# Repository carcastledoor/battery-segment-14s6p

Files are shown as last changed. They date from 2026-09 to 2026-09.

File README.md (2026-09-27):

# Formula EV 배터리 · 포트폴리오 근거 자료

제출 포트폴리오 **「AI와 함께 설계한 Formula EV 배터리」**에서 소개한 계산기와 후속 3D 설계 파일입니다. 발표자료의 해당 페이지를 보면서 계산 과정과 실제 설계 산출물을 확인할 수 있습니다.

## 포트폴리오에서 확인할 자료로

| 포트폴리오 | 이 저장소의 자료 | 확인할 내용 |
|---|---|---|
| **7장 · AI 설계 도구** | **[Excel 계산기 다운로드](site/documents/battery-pack-calculator.xlsx)** | 셀 DB 조회, S/P 입력, 전압·용량·에너지·질량·배치 치수 수식 |
| **8장 · 설계안 비교** | **[후보 비교 재현 방법](docs/CALCULATOR.md)** | 24S에서 8P·10P·12P·14P를 대입해 발표자료의 비교값 확인 |
| **17장 · 자연어 기반 3D 설계 확장** | **[모델 확인 안내](docs/VIEWER.md)** · [설계 파일 설명](docs/DESIGN.md) | P45B 세그먼트, 배터리박스, 전장품 배치와 조립·분해 구조 |

**계산기를 먼저 확인하려면:** Excel의 `Battery_Calculator`에서 저장된 Samsung 50S·24S12P 입력과 결과를 확인하세요. 288셀·86.4V·60Ah·5.184kWh가 발표자료의 예시입니다. 8장의 비교는 병렬 수를 바꿔 재현합니다.

**3D 설계를 확인하려면:** 최신 뷰어의 Segment와 Battery Box를 확인하세요. 현재 공개된 실행 주소는 등록되지 않았습니다. [모델 확인 안내](docs/VIEWER.md)에 다운로드와 로컬 실행 방법을 정리했습니다.

## 자료의 범위

계산기는 **2025 실물 프로젝트의 50S·24S12P 설계 탐색**을, 3D 파일은 **17장의 후속 P45B·70S6P 설계 확장**을 뒷받침합니다. 두 설계는 서로 다른 프로젝트 단계입니다.

실물 제작·고장 진단·검차 결과는 포트폴리오 13–16장의 사진과 기록을 참고하세요. 이 저장소의 계산기·후속 모델은 해당 실물 결과를 대신하는 시험 증빙이 아닙니다. [검증 범위](docs/VALIDATION.md)

<details>
<summary>파일 위치</summary>

- `site/documents/`: 계산기 원본
- `site/`: 최신 통합 뷰어
- `docs/`: 계산 재현·모델 설명·확인 범위
- `downloads/`: 배포용 ZIP

비공개 저장소이므로 링크로 검토하려면 접근 권한이 필요합니다. 이전 파일은 Git 이력에 보존되어 있습니다.

</details>

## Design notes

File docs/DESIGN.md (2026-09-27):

# 포트폴리오 17장 · 후속 3D 설계

[처음으로](../README.md)

이 자료는 발표자료 17장의 **자연어 요구 → 3D 형상 → 반복 수정**으로 확장한 설계 산출물입니다. 2025년 제작한 50S 팩의 CAD가 아니라, 당시의 조립·정비 경험을 반영한 다음 시즌 P45B 설계 초안입니다.

## 모델에서 확인할 항목

| 화면 | 확인할 설계 내용 |
|---|---|
| Segment | 셀·홀더·구리/니켈 연결판, A/B 단자 배치, 센싱 PCB와 팬 구조 |
| Battery Box | 5개 세그먼트, 상부 전장품 공간, 버스바 경로, 조립·분해 순서 |
| Description | 셀 선정 기준과 계산기를 패키징에 연결한 설명 |

발표자료의 BMS–버스바 간섭 수정 사례와 연결해 전장품 배치를 볼 수 있습니다. 현재 파일에 모든 수정 단계가 보존된 것은 아니며, 슬라이드의 약 5mm 여유를 독립적으로 재측정한 검사 성적서는 포함하지 않습니다.

## 현재 설계의 계산 기준

사용 셀은 Molicel P45B입니다. 셀 데이터와 직·병렬 수를 직접 만든 계산기에 적용해 전압, 용량, 에너지, 셀 개수와 셀 질량을 검토했습니다.

| 항목 | 현재 설계 기준 |
|---|---:|
| 전체 구성 | 70S6P, 420셀 |
| 세그먼트 | 14S6P × 5개 |
| 공칭 / 최대 전압 | 252V / 294V |
| 용량 / 공칭 에너지 | 27Ah / 6.804kWh |
| 셀 질량 합계 | 28.98kg (69g/셀 기준, 케이스·전장품 제외) |

[계산기 원본](../site/documents/battery-pack-calculator.xlsx)의 저장된 입력은 Samsung 50S·24S12P 예시입니다. 위 수치는 P45B·70S6P를 같은 계산 관계에 적용한 값이며 저장된 입력값과 구분해야 합니다. 셀 정격 전류의 병렬 합을 팩의 검증된 허용 전류로 취급하지 않습니다.

## 패키징으로 연결

- 14S6P 세그먼트의 A/B 단자 배치를 이용해 B–A–B–A–B로 배치합니다.
- 셀 연결부는 니켈 용접 패치와 구리 연결판으로 구성하고, V2 끝단은 ㄱ자 일체형 연결 구조입니다.
- 세그먼트 팬 방향을 통일하고, 하부 세그먼트 공간과 상부 전장품 공간을 구분합니다.
- 양극 전력 경로는 세그먼트 → 퓨즈 → AIR+ → 외부 고전압 커넥터입니다. 음극은 AIR−를 거칩니다.
- 센싱 PCB, BMS, 온도 확장모듈, IMD의 배치와 커넥터 접근 공간을 함께 검토합니다.
- 뚜껑의 안·바깥 측벽이 박스 벽을 감싸며, 팝너트는 뚜껑 안쪽 벽에 배치합니다.
- 조립·분해 화면은 정비 동선을 검토하기 위한 표현입니다. 용접·영구 고정부는 독립적으로 분해하지 않습니다.

배터리박스의 차량 체결 방식은 아직 결정하지 않았습니다. 차량 프레임 화면은 참고 형상이며 장착 설계 확정을 뜻하지 않습니다.

셀 상세, 배열 계산식 및 설계 근거는 웹 뷰어의 Description에서도 확인할 수 있습니다.

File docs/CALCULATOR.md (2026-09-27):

# 포트폴리오 7–8장 · 계산 근거

[처음으로](../README.md) · [계산기 다운로드](../site/documents/battery-pack-calculator.xlsx)

원본 파일은 수정하지 않았습니다. `Battery_Calculator`와 `Cell_DB` 두 시트로 구성됩니다. 셀 모델, S/P, 가로·세로 셀 수, 간격, 방향, 여유를 입력하고 셀 DB를 조회해 결과를 계산합니다.

## 7장 예시 재현

`Battery_Calculator!B4:B6`의 저장값은 Samsung INR21700-50S, 24, 12입니다. `Cell_DB!C4:J4`에 공칭 3.6V, 최대 4.2V, 최소 2.5V, 5Ah, 25A, 72g, 지름 21.45mm, 높이 70.55mm가 있습니다.

| 출력 셀 | 계산 | 결과 |
|---|---|---|
| B16 | 24 × 12 | 288셀 |
| D16 / F16 | 24 × 3.6 / 24 × 4.2 | 공칭 86.4V / 최대 100.8V |
| H16 | 12 × 5Ah | 60Ah |
| B18 | 86.4 × 60 / 1000 | 5.184kWh |
| D18 | 12 × 25A | 셀 정격 합산 300A |
| F18 | 86.4 × 300 / 1000 | 공칭 기준 계산값 25.92kW |
| H18 | 288 × 72g / 1000 | 셀만 20.736kg |

## 8장 후보 비교 재현

발표자료 8장의 비교는 B6을 8, 10, 12, 14로 바꿔 하나씩 재현할 수 있습니다. 동시 비교표나 자동 최적화 기능이 구현된 파일은 아닙니다. PPT에서 설명한 요구조건을 기준으로 사람이 후보를 선택하는 도구입니다.

| 병렬 수 | 합산 전류 A | 에너지 kWh | 셀 질량 kg |
|---|---:|---:|---:|
| 8 | 200 | 3.456 | 13.824 |
| 10 | 250 | 4.320 | 17.280 |
| 12 | 300 | 5.184 | 20.736 |
| 14 | 350 | 6.048 | 24.192 |

## 해석 범위

- B20/D20/F20은 셀 치수·간격·여유를 이용한 직육면체 적층 추정입니다. 현재 입력은 12 × 4 × 6층, 285.4 × 97.8 × 439.3mm입니다. 실물의 4S12P 세그먼트 6개 배치나 후속 70S6P 박스 외형을 직접 산출한 값이 아닙니다.
- 300A와 25.92kW는 저장된 셀 정격을 단순 합산한 선별값입니다. 냉각·전압 강하·배선·접촉저항을 반영한 팩 보증 정격이 아닙니다.
- 질량은 셀만 포함하며 케이스·배선·냉각·전장품 질량을 포함하지 않습니다.
- Cell_DB 출처에는 제조사와 제3자 자료가 함께 있습니다. 본 검토에서는 모든 셀의 공식 정격을 재확인하지 않았습니다.

## 확인한 항목

저장된 입력·수식·캐시 결과를 읽고 위 결과와 4개 병렬 후보를 독립 산술 계산으로 대조했습니다. Excel 앱에서 입력 변경에 따른 재계산이나 화면 렌더링은 확인하지 않았습니다. 원본 파일과 첨부 사본의 SHA-256 일치를 확인합니다.

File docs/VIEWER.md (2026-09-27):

# 포트폴리오 17장 · 모델 확인 방법

[근거 자료 목록](../README.md) · [설계 파일 설명](DESIGN.md)

최신 모델은 **Battery Design Files**에 들어 있습니다. Segment에서 세그먼트를, Battery Box에서 전체 팩과 전장품 배치를 확인하세요. Description은 설계 과정 설명입니다. Frame은 참고 형상이며 차량 체결 방식은 미정입니다.

## 모델 파일 열기

현재 공유용 웹 주소는 등록되지 않았습니다. [최신 뷰어 ZIP](../downloads/Battery-Design-Files-Netlify.zip)을 내려받아 압축을 해제하면 모델 파일 전체를 받을 수 있습니다.

Python 3가 설치된 경우 압축을 푼 폴더에서 다음을 실행한 뒤 **http://localhost:8000**을 엽니다.

```sh
python3 -m http.server 8000
```

이 뷰어는 HTTP/HTTPS로 데이터를 읽습니다. HTML 더블클릭만으로 실행되지는 않습니다. 최신 브라우저의 WebGL과 gzip 압축 해제 기능을 사용합니다.

## 확인할 동작

- 드래그로 회전하고 휠로 확대합니다.
- 시점 버튼으로 상부·측면 등을 확인합니다.
- **↑를 누르면 분해, ↓를 누르면 조립**됩니다. 길게 누르거나 슬라이더로 단계를 조절할 수 있습니다.
- 부품 표시 메뉴로 전장품과 내부 구조를 나눠 봅니다.

<details>
<summary>제출자용 · 웹 주소를 만드는 방법</summary>

[Netlify Drop](https://app.netlify.com/drop)에 위 ZIP을 업로드합니다. 저장소 연동 방식이라면 빌드 명령 없이 `site`를 배포 폴더로 지정합니다. 발급된 주소를 README에 등록하면 심사위원이 설치 없이 열 수 있습니다.

배포 시 site 안의 모델과 계산기를 방문자가 내려받을 수 있습니다. `assets`, `data`, `documents`는 함께 유지해야 합니다.

</details>

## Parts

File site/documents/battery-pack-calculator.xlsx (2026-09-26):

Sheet: Battery_Calculator
Formula Student Battery Pack Calculator
INPUT |  |  |  | SELECTED CELL SPEC
셀 모델 | Samsung INR21700-50S |  |  | Nominal V | 3.60 | Max V | 4.20
S 직렬 수 | 24 |  |  | Min V | 2.50 | Capacity Ah | 5.00
P 병렬 수 | 12 |  |  | Continuous A | 25.00 | Weight g | 72.00
가로 셀 수 X | 12 |  |  | Diameter mm | 21.45 | Height mm | 70.55
세로 셀 수 Y | 4 |  |  | Format | 21700.00
셀 간격 mm | 2
셀 방향 | 세워서
외곽 여유 mm | 3
층간 간격 mm | 2
OUTPUT
총 셀 수 | 288 | 공칭 전압 V | 86.40 | 최대 전압 V | 100.80 | 용량 Ah | 60.00
에너지 kWh | 5.18 | 연속 허용전류 A | 300.00 | 연속 출력 kW | 25.92 | 셀 총질량 kg | 20.74
Pack 가로 mm | 285.40 | Pack 세로 mm | 97.80 | Pack 높이 mm | 439.30 | 배치 X×Y×Layer | 12 × 4 × 6

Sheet: Cell_DB
Cell Model | Format | Nominal V | Max V | Min V | Capacity Ah | Continuous A | Weight g | Diameter mm | Height mm | Source URL
Samsung INR18650-30Q | 18650 | 3.6 | 4.2 | 2.5 | 3 | 15 | 48 | 18.33 | 64.85 | https://www.orbtronic.com/samsung-18650-30q-3000mah-15a-high-drain-battery-flat-top
Samsung INR21700-40T | 21700 | 3.6 | 4.2 | 2.5 | 4 | 35 | 70 | 21.22 | 70.3 | https://files.batteryjunction.com/frontend/files/samsung/datasheet/SAMSUNG-40T-Datasheet.pdf
Samsung INR21700-50S | 21700 | 3.6 | 4.2 | 2.5 | 5 | 25 | 72 | 21.45 | 70.55 | https://www.dnkpower.com/samsung-inr21700-50s/
Molicel INR18650-P28A | 18650 | 3.6 | 4.2 | 2.5 | 2.8 | 35 | 46 | 18.6 | 65.2 | https://www.molicel.com/product/inr-18650-p28a/
Molicel INR21700-P42A | 21700 | 3.6 | 4.2 | 2.5 | 4.2 | 45 | 70 | 21.7 | 70.2 | https://www.molicel.com/product/inr-21700-p42a/
Molicel INR21700-P45B | 21700 | 3.6 | 4.2 | 2.5 | 4.5 | 45 | 69 | 21.6 | 70.2 | https://www.molicel.com/product/inr-21700-p45b/
Molicel INR21700-P50B | 21700 | 3.6 | 4.2 | 2.5 | 5 | 60 | 71 | 21.55 | 70.15 | https://www.molicel.com/product/inr-21700-p50b/
Murata US18650VTC6 | 18650 | 3.6 | 4.2 | 2 | 3.12 | 30 | 46.6 | 18.5 | 65.2 | https://www.murata.com/-/media/webrenewal/products/batteries/cylindrical/datasheet/us18650vtc6-product-datasheet.ashx
Murata US21700VTC6A | 21700 | 3.6 | 4.2 | 2.5 | 4.1 | 40 | 67.5 | 21 | 70 | https://www.murata.com/products/batteries/cylindrical
Samsung INR21700-50E | 21700 | 3.6 | 4.2 | 2.5 | 4.9 | 9.8 | 69 | 21.25 | 70.8 | https://www.dnkpower.com/li-ion-18650-battery/

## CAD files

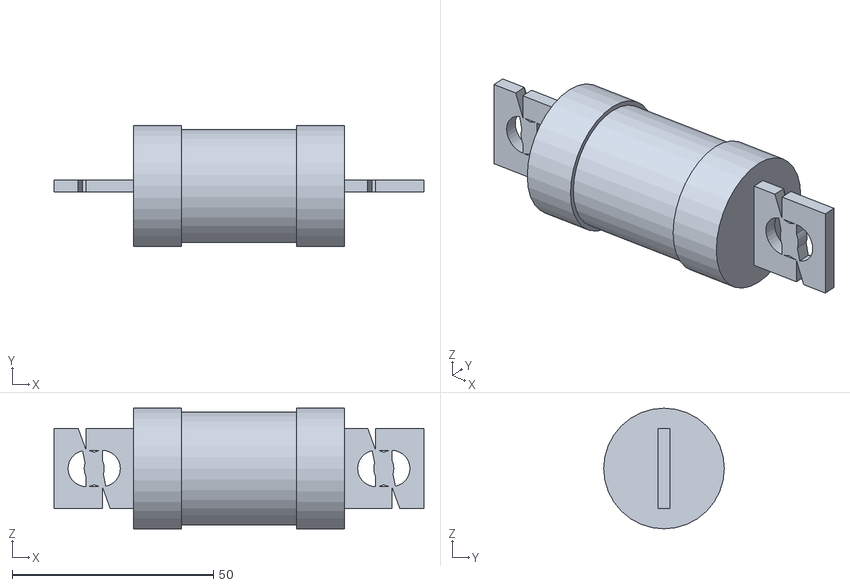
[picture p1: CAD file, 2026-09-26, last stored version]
portfolio/models/pack-mainfuse.stl
92.0 x 30.0 x 30.0

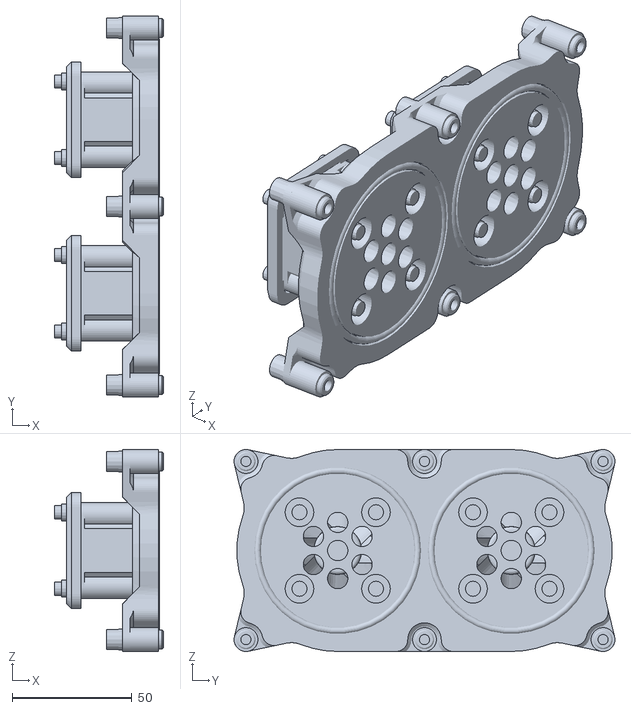
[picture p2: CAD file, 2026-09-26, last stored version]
portfolio/cad/cooling/Outlet-display.stl
45.5 x 159.4 x 84.5

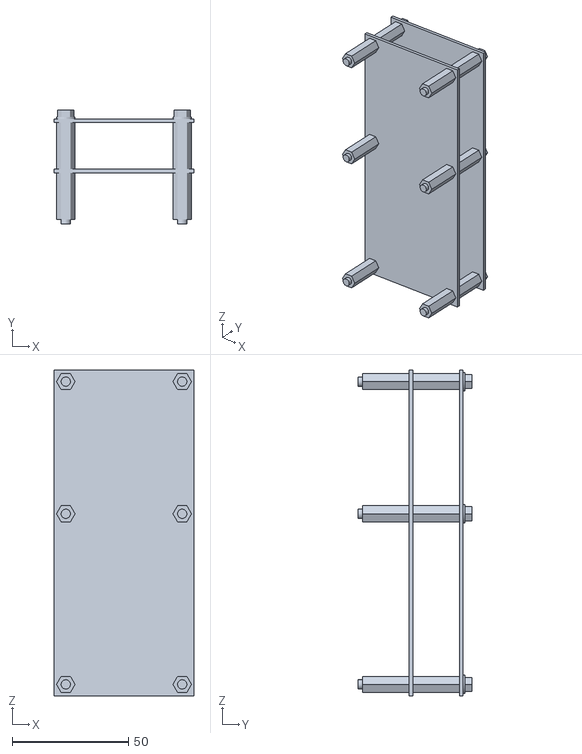
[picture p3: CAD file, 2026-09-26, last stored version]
portfolio/models/pack-imdstack.stl
60.0 x 49.0 x 140.0

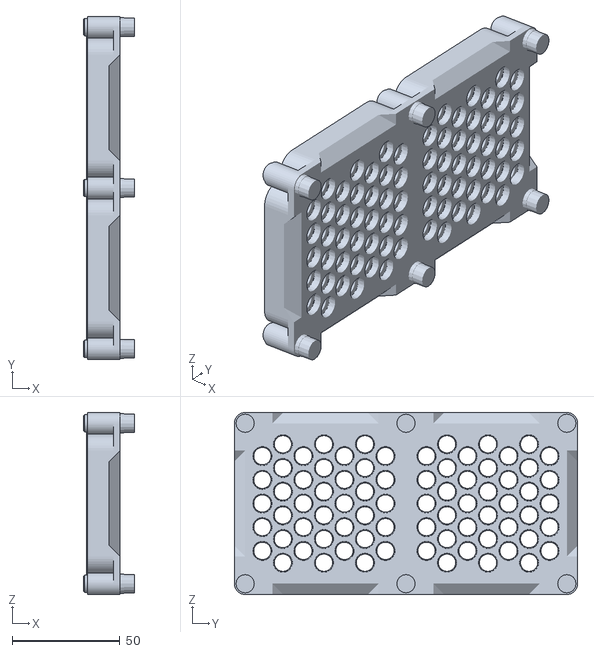
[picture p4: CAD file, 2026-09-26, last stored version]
portfolio/cad/cooling/Inlet-display.stl
23.8 x 159.4 x 84.5

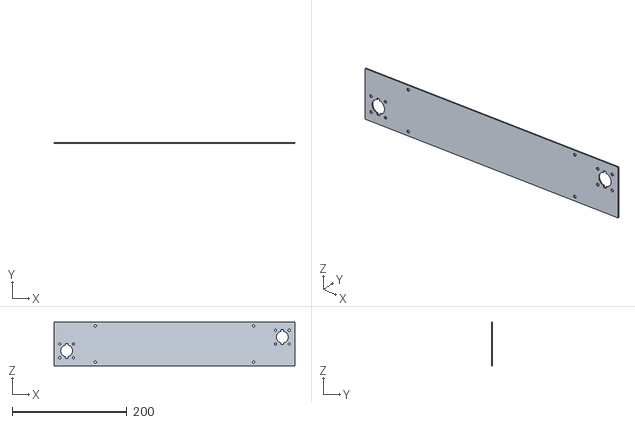
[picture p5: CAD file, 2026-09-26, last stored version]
portfolio/models/A-pcb.stl
420.0 x 1.62 x 76.4

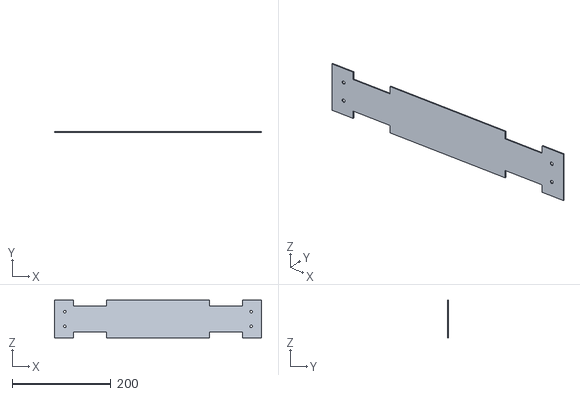
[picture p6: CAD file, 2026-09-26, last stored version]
portfolio/models/B-bottomcase.stl
420.0 x 1.60 x 76.4

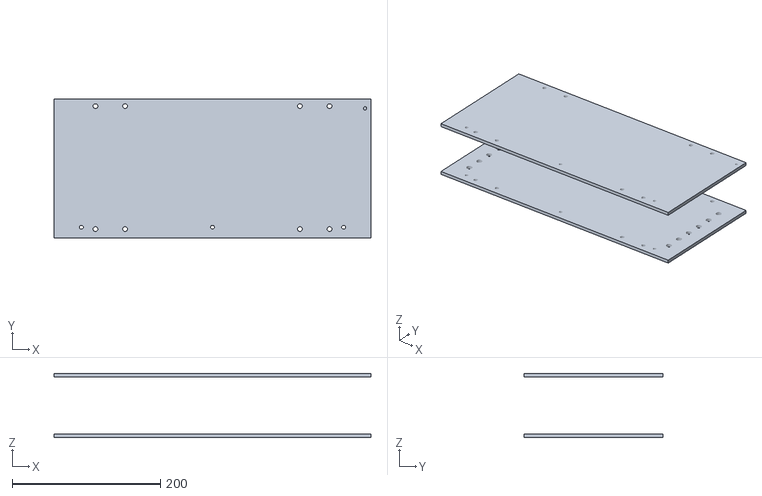
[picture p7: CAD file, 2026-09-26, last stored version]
portfolio/models/B-covers.stl
428.0 x 187.6 x 86.8

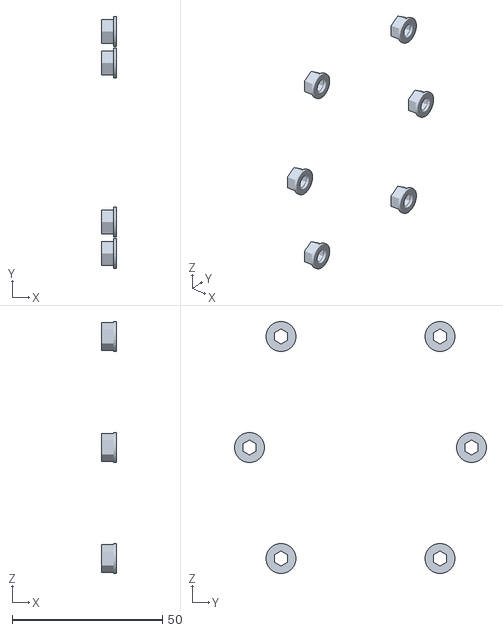
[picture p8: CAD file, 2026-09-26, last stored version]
portfolio/models/pack-panelmountnuts.stl
5.00 x 84.0 x 84.0

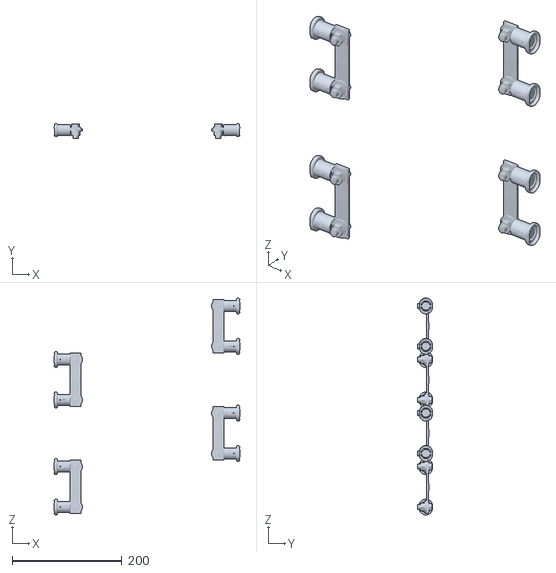
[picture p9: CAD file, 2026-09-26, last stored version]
portfolio/models/pack-shrinkwrap.stl
338.7 x 27.3 x 395.6

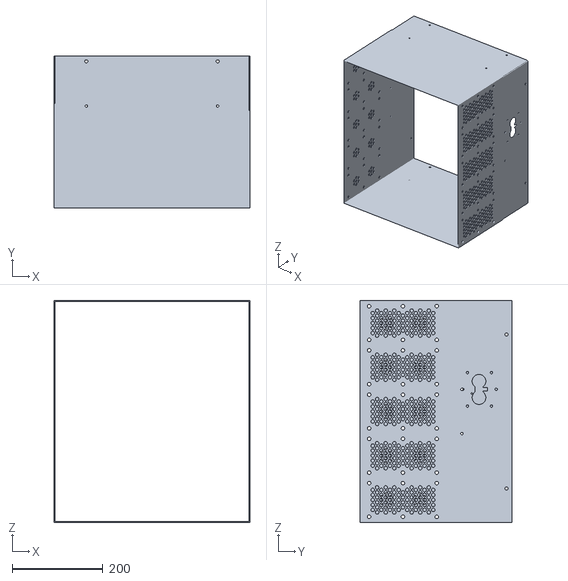
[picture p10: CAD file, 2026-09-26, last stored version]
portfolio/models/pack-boxwalls.stl
432.7 x 335.9 x 490.1

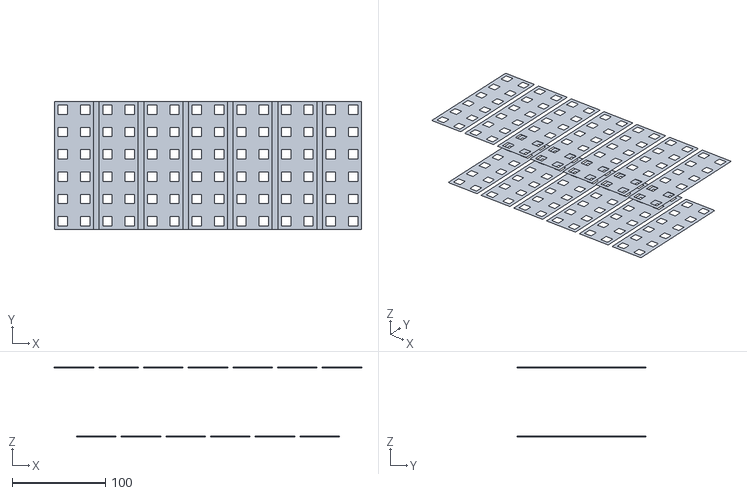
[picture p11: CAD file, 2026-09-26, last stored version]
portfolio/models/B-bridges.stl
330.0 x 138.0 x 74.3

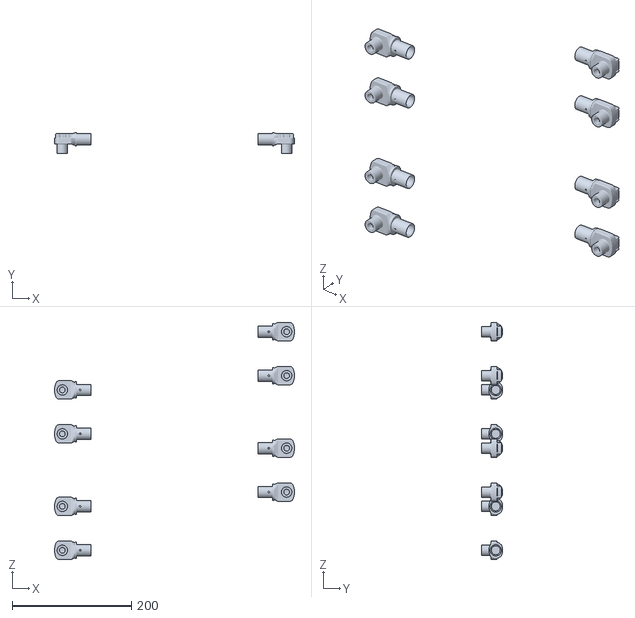
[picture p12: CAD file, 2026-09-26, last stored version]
portfolio/models/pack-powerplugs.stl
402.4 x 35.2 x 397.5

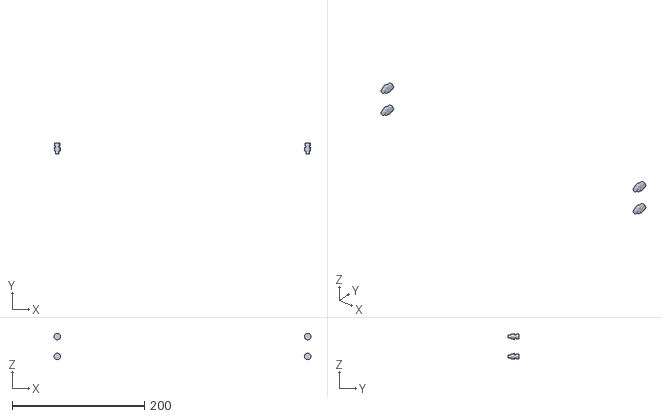
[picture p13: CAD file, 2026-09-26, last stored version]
portfolio/models/B-casefasteners.stl
388.0 x 16.0 x 40.0

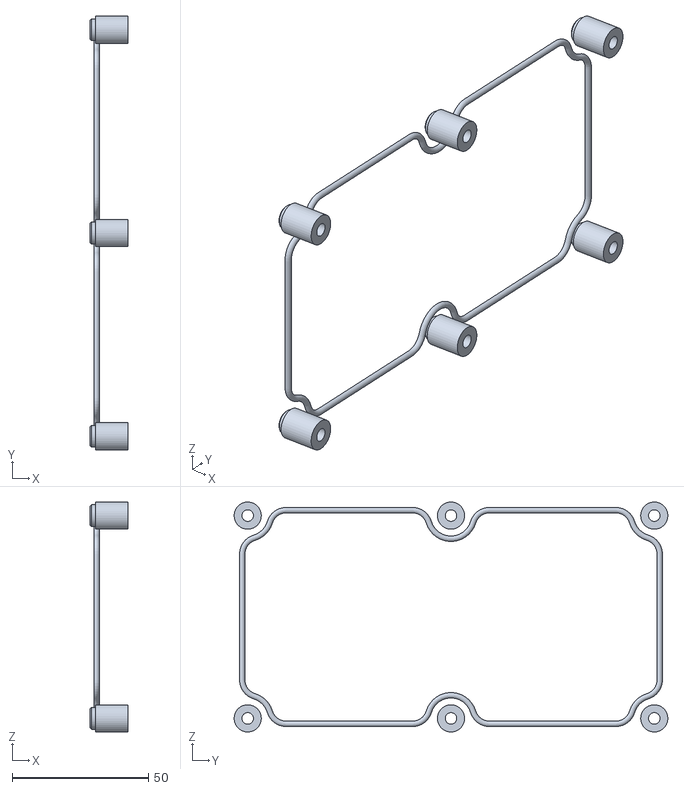
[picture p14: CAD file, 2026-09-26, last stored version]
portfolio/models/pack-coolingSeals.stl
14.0 x 159.4 x 84.5

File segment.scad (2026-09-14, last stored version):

// 14S6P segment — dimensional concept, not a fabrication release.
// Units: mm. Open in OpenSCAD. Edit parameters; F5 preview, F6 render.
// Export one part at a time with part="holder" / "bridge" / "terminal".
$fn=64;
series=14;
parallel=6;
cell_d=21.55;
cell_l=70.15;
pitch=24;
edge=15;
holder_t=4;
seat_depth=2.5;
clearance=0.30;
access_d=18;
bridge_w=42;
bridge_t=0.30; // Placeholder only: conductor sizing NOT evaluated.
terminal_w=28;
endplate_contact_w=18;
terminal_t=2; // Placeholder only.
terminal_hole=5.5;
terminal_tab=40;
terminal_side_gap=3;
terminal_overlap=12;
pcb_t=1.6;
pcb_gap=2;
pcb_cell_gap=2;
pcb_edge=4;
ear_w=66;
ear_h=16;
mount_hole=6.5;
explode=0;
part="assembly";
show_cells=true;
show_holders=true;
show_bridges=true;
show_terminals=true;
show_pcb=true;
W=(series-1)*pitch+2*edge;
H=(parallel-1)*pitch+2*edge;
bridge_h=(parallel-1)*pitch+18;
function cx(c)=(c-(series-1)/2)*pitch;
function cy(r)=(r-(parallel-1)/2)*pitch;
outer=cell_l/2+holder_t-seat_depth;
module holder(){
 difference(){
  union(){
   translate([-W/2,-H/2,0]) cube([W,H,holder_t]);
   for(sx=[-1,1],sy=[-1,1]) translate([sx*(W/2-ear_w/2),sy*(H/2+ear_h/2),holder_t/2]) cube([ear_w,ear_h,holder_t],center=true);
  }
  for(sx=[-1,1],sy=[-1,1],dx=[-20,20]) translate([sx*(W/2-ear_w/2)+dx,sy*(H/2+ear_h/2),-0.01]) cylinder(d=mount_hole,h=holder_t+0.02);
  for(c=[0:series-1],r=[0:parallel-1]) translate([cx(c),cy(r),0]) {
   translate([0,0,-0.01]) cylinder(d=cell_d+clearance,h=seat_depth+0.01);
   translate([0,0,-0.01]) cylinder(d=access_d,h=holder_t+0.02);
  }
 }
}
module cell(c,r){
 translate([cx(c),cy(r),0]) {
  color([0.06,0.42,0.32]) cylinder(d=cell_d,h=cell_l,center=true);
  for(s=[-1,1]) translate([0,0,s*(cell_l/2+0.03)])
   color((c%2==0 && s==1)||(c%2==1 && s==-1)?[0.85,0.88,0.88]:[0.55,0.61,0.63])
   cylinder(d=((c%2==0 && s==1)||(c%2==1 && s==-1))?9:17,h=0.06,center=true);
 }
}
module bridge(){translate([-bridge_w/2,-bridge_h/2,0]) cube([bridge_w,bridge_h,bridge_t]);}
cell_top=(parallel-1)*pitch/2+cell_d/2;
pcb_y=cell_top+pcb_cell_gap;
terminal_top=pcb_y-pcb_gap;
terminal_base=-outer-0.3-bridge_t-terminal_t;
terminal_x=W/2+terminal_side_gap+terminal_w/2;
endplate_inner=(series-1)*pitch/2-endplate_contact_w/2;
endplate_outer=W/2+terminal_side_gap+terminal_overlap;
terminal_hole_z=terminal_base+terminal_tab-9;

pcb_depth=cell_l-2*seat_depth-1;
pcb_width=W+2*(terminal_side_gap+terminal_w+pcb_edge);
module terminal(){
 // Outboard busbar: lap-connected to the lateral extension of the end Ni/Cu plate.
 // Local Z starts at the rear outside surface and increases into the segment.
 // Sharp bend is a concept approximation; actual bend radius is unassigned.
 difference(){
  union(){
   translate([-terminal_w/2,-bridge_h/2,0]) cube([terminal_w,terminal_top+bridge_h/2,terminal_t]);
   translate([-terminal_w/2,terminal_top-terminal_t,0]) cube([terminal_w,terminal_t,terminal_tab]);
  }
  translate([0,terminal_top+1,terminal_tab-9]) rotate([90,0,0]) cylinder(d=terminal_hole,h=terminal_t+2);
 }
}
module endplate(){
 translate([endplate_inner,-bridge_h/2,0]) cube([endplate_outer-endplate_inner,bridge_h,bridge_t]);
}
module pcb(){
 difference(){
  translate([-pcb_width/2,0,-pcb_depth/2]) cube([pcb_width,pcb_t,pcb_depth]);
  for(side=[-1,1]) translate([side*terminal_x,pcb_t+0.1,terminal_hole_z]) rotate([90,0,0]) cylinder(d=terminal_hole,h=pcb_t+0.2);
 }
}
module assembly(){
 if(show_cells) for(c=[0:series-1],r=[0:parallel-1]) cell(c,r);
 if(show_holders) for(s=[-1,1]) color([0.12,0.14,0.16])
  scale([1,1,s]) translate([0,0,cell_l/2-seat_depth+explode]) holder();
 // Alternating polarity columns: front links 1-2,3-4,...13-14;
 // rear links 2-3,4-5,...12-13. Both outputs at rear end columns.
 if(show_bridges) for(c=[0:series-2]) let(s=c%2==0?1:-1)
  color([0.72,0.47,0.23]) scale([1,1,s])
  translate([(cx(c)+cx(c+1))/2,0,outer+0.3+2*explode]) bridge();
 if(show_bridges) for(side=[-1,1]) color([0.72,0.47,0.23])
  scale([side,1,1]) translate([0,0,-outer-0.3-bridge_t-2*explode]) endplate();
 if(show_terminals) for(side=[-1,1]) color([0.88,0.40,0.12])
  translate([side*terminal_x,0,terminal_base-2*explode]) terminal();
 if(show_pcb) color([0.12,0.42,0.32]) translate([0,pcb_y+3*explode,0]) pcb();
}
assert(pitch>cell_d+clearance,"Pitch must exceed pocket diameter");
assert(series%2==0,"This terminal arrangement assumes an even series count");
assert(bridge_w<2*pitch,"Adjacent bridge plates must remain separated");
if(part=="assembly") assembly();
else if(part=="holder") holder();
else if(part=="bridge") bridge();
else if(part=="terminal") terminal();
else if(part=="pcb") pcb();
else if(part=="endplate") endplate();
echo(holder_dimensions=[W,H,holder_t],cells=series*parallel);

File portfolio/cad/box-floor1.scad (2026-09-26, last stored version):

// Box base, outer walls and partitions: aluminum; alloy unspecified.
// V2 A/B: A=0 degrees, B=180 degrees about vertical Y. Standalone V2 unchanged.
// Units mm; Y is vertical. First floor with second-floor deck draft. Segment source preserves approved draft.
include <segment-source.scad>
box_wall=2;box_base=4;box_inner_x=428.66;box_inner_z=486.125;box_h=230.4;slot_pitch=97.625;
partition_top=93.4;partition_h=208.6;deck_t=2;deck_edge=.5;deck_hole=44;show_floor2=true;
show_segments=true;show_box=true;show_partitions=true;
module floor1_shell(){
 color([.76,.78,.80])translate([0,-box_h/2-box_base/2,0])cube([box_inner_x+2*box_wall,box_base,box_inner_z+2*box_wall],center=true);
 color([.76,.78,.80])import("../models/pack-boxwalls.stl");
}
if(show_box)floor1_shell();
if(show_partitions)for(i=[0:3])color([.76,.78,.80])translate([0,(-box_h/2+partition_top)/2,(i-1.5)*slot_pitch])cube([box_inner_x,partition_h,box_wall],center=true);
if(show_segments)for(i=[0:4])translate([0,95-box_h/2,(i-2)*slot_pitch])rotate([0,i%2==0?180:0,0])let($layout_hand=i%2==0?-1:1)assembly();

// Original cooling assemblies, simplified display threads; exact geometry in STEP.
show_cooling=true;
// External outlet fans removed; retain inlet/filter assemblies.
if(show_cooling)for(i=[0:4])for(side=[1])color([.25,.28,.30])translate([side*(box_inner_x/2+box_wall),95-box_h/2,(i-2)*slot_pitch])import(side==1?"cooling/Inlet-display.stl":"cooling/Outlet-display.stl");

module floor2_deck(){color([.76,.78,.80])import("../models/pack-floor2.stl");}
if(show_floor2)floor2_deck();

include <equipment-layout.scad>
show_non_hv=true;show_equipment=true;show_power_routing=true;
if(show_equipment)equipment_layout();
if(show_power_routing)routing_layout();


// Lid skirt overlaps the existing inner box wall; M5 rivet nut sizes provisional.
show_lid=true;
if(show_lid){
 color([.76,.78,.80])import("../models/pack-lidtop.stl");
 color([.70,.73,.76])import("../models/pack-lidlocating.stl");
 color([.65,.68,.70])import("../models/pack-lidbolts.stl");
}
color([.65,.68,.70])import("../models/pack-lidrivnuts.stl");

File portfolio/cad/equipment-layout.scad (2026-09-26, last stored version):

// Current tessellated packaging concept. Generated from preview; standalone V2 unchanged.
module equipment_layout(){
color([0.07, 0.3, 0.16])import("../models/pack-imdstack.stl");
color([0.65, 0.68, 0.7])import("../models/pack-equipmentbolts.stl");
color([0.65, 0.68, 0.7])import("../models/pack-captivenuts.stl");
color([0.72, 0.36, 0.16])import("../models/pack-packnegative.stl");
color([0.65, 0.68, 0.7])import("../models/pack-packrings.stl");
color([0.65, 0.68, 0.7])import("../models/pack-packfasteners.stl");
color([0.65, 0.68, 0.7])import("../models/pack-packplugs.stl");
color([0.98, 0.255, 0.018])import("../models/pack-fixedshrink.stl");
color([0.65, 0.68, 0.7])import("../models/pack-sensingmates.stl");
color([0.65, 0.68, 0.7])import("../models/pack-deckbrackets.stl");
color([0.65, 0.68, 0.7])import("../models/pack-deckbolts.stl");
color([0.65, 0.68, 0.7])import("../models/pack-equipmentmounts.stl");
color([0.65, 0.68, 0.7])import("../models/pack-airnuts.stl");
color([0.65, 0.68, 0.7])import("../models/pack-airwashers.stl");
color([0.65, 0.68, 0.7])import("../models/pack-panelmountbolts.stl");
color([0.65, 0.68, 0.7])import("../models/pack-panelmountnuts.stl");
color([0.94, 0.25, 0.015])import("../models/pack-hvpanel.stl");
color([0.65, 0.68, 0.7])import("../models/pack-mainfuse.stl");
color([0.72, 0.36, 0.16])import("../models/pack-fuselinks.stl");
color([0.65, 0.68, 0.7])import("../models/pack-fusebolts.stl");
color([0.98, 0.255, 0.018])import("../models/pack-shrinkwrap.stl");
color([0.72, 0.36, 0.16])import("../models/pack-hvoutput.stl");
color([0.65, 0.68, 0.7])import("../models/pack-hvoutputbolts.stl");
color([0.3, 0.32, 0.34])import("../models/pack-bms.stl");
color([0.12, 0.12, 0.12])import("../models/pack-thermistor.stl");
color([0.07, 0.3, 0.16])import("../models/pack-imd.stl");
color([0.45, 0.45, 0.45])import("../models/pack-airs.stl");
color([0.65, 0.68, 0.7])import("../models/pack-powerplugs.stl");
color([0.72, 0.36, 0.16])import("../models/pack-powercables.stl");
color([0.65, 0.68, 0.7])import("../models/pack-ringadapters.stl");
color([0.65, 0.68, 0.7])import("../models/pack-hvfasteners.stl");
color([0.65, 0.68, 0.7])import("../models/pack-imdmounts.stl");
}
module routing_layout(){}

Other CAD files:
portfolio/models/pack-fuselinks.stl
portfolio/models/pack-hvfasteners.stl
portfolio/models/pack-airs.stl
portfolio/cad/fan-mesh.scad
archive/previous-portfolio/portfolio/cad/fan-mesh.scad
archive/previous-portfolio/portfolio/cad/segment-source.scad
archive/previous-portfolio/portfolio/models/A-busbarcradles.stl
archive/previous-portfolio/portfolio/models/A-casefasteners.stl
archive/previous-portfolio/portfolio/models/A-cells.stl
archive/previous-portfolio/portfolio/models/A-covermounts.stl
archive/previous-portfolio/portfolio/models/A-covers.stl
archive/previous-portfolio/portfolio/models/A-fanmount.stl
archive/previous-portfolio/portfolio/models/A-fans.stl
archive/previous-portfolio/portfolio/models/A-handles.stl
archive/previous-portfolio/portfolio/models/A-hardware.stl
archive/previous-portfolio/portfolio/models/A-holders.stl
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

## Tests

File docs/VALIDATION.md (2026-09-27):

# 확인한 범위와 남은 검토

[처음으로](../README.md)

## 배포 파일 확인

- 최신 배포본 25개 파일, ZIP 약 48.8MB, ZIP 루트에 index.html 포함
- 압축 데이터 해제와 원본 바이트 일치 확인
- HTTP를 통한 세그먼트·박스·프레임 로딩 및 실제 모델 엔진의 그리기 호출 확인
- 내부 페이지 구조, 링크, 키보드 유지·해제, 슬라이더 동기화 검사

그리기 검사는 기록용 WebGL 컨텍스트를 사용했습니다. 실제 브라우저 GPU 화면·실기기 조작 및 실제 Netlify 배포 완료를 의미하지 않습니다.

## 설계 검증 경계

이 모델은 제작 승인 도면이 아닙니다. 열·구조·절연 성능, 단락 전류, 퓨즈 차단용량, 버스바 정격, 공차 및 실제 공구 접근성은 별도 검증이 필요합니다. 차량 체결 방식은 미정입니다.

계산기/제조사 최대 셀 치수 21.6 × 70.2mm와 기존 형상의 21.55 × 70.15mm 사이에는 차이가 있습니다. 제작용 홀더 치수 확정 시 확인해야 합니다.

이전 CAD/STL·부품표는 Git 이력에만 보존했습니다. 최신 웹 모델과 일치하는 제작 도면·BOM은 확정하지 않았습니다.

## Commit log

2026-09-14 Add P45B 14S6P model and Windows sharing package
    Include the standalone 3D preview, editable OpenSCAD model, dimensions, preview image and Windows ZIP. Reflect 28 mm outboard busbars, lowered PCB and aligned 5.5 mm terminal holes.
    [segment.scad]
2026-09-26 Add 70S6P battery pack portfolio and reviewer packages
    [A-bottomcase.stl, A-bridges.stl, A-busbarcradles.stl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]
2026-09-26 Connect hackathon story with calculator and offline supporting materials
    [Formula_Student_Battery_Pack_Calculator_Rebuilt.xlsx]
2026-09-27 Organize latest battery design viewer and newcomer documentation
    [A-bottomcase.stl, A-bridges.stl, A-busbarcradles.stl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]
2026-09-27 Streamline reviewer guide and remove superseded portfolio files
    [A-bottomcase.stl, A-bridges.stl, A-busbarcradles.stl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]
2026-09-27 Remove portfolio presentation from supporting materials
